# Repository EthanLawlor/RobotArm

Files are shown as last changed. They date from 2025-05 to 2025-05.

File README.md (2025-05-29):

# 🤖 Desktop Robot Arm

A compact, fully customizable desktop robot arm designed for small-scale automation tasks. Developed as part of a Bachelor of Engineering in Mechatronics at Technological University Dublin, this project integrates 3D-printed components, servo motor actuation, custom electronics, Arduino-based firmware, Bluetooth control, and an Android app interface.

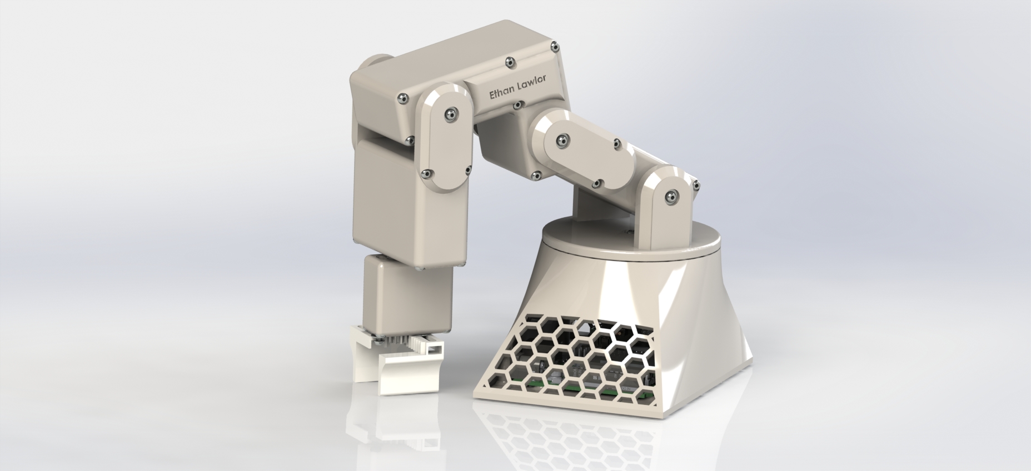
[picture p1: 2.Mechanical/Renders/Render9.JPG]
Robot Arm CAD Render
  
*Figure: CAD render of the assembled Desktop Robot Arm*

---

## 📦 Features

- 6 Degrees of Freedom using MG66R and SG90 servo motors  
- Bluetooth-enabled control with HC-05 and MIT App Inventor  
- Android app with presets and direct manual controls  
- Custom PCB with schematics and Gerber files (KiCAD)  
- Modular 3D-printed design with STL files included  
- Smooth servo motion using filtering algorithms  

---

## 📁 Repository Structure

1. **Documentation**  
   - `RobotArm-ProjectReport.pdf` – Full project report with design, testing, and results

2. **Electrical**  
   - `KiCAD-PCB/` – Circuit schematics, custom PCB layout, and Gerber files

3. **Mechanical**  
   - `STL-Files/` – 3D-printable mechanical components  
   - Includes exploded views and CAD drawings

4. **Software**  
   - `Arduino-Firmware/` – Code for ATmega328P (Arduino)  
   - `MIT-App-Inventor/` – Android app `.aia` source and `.apk` installer

---

## 🔧 Hardware Overview

- **Microcontroller:** ATmega328P (Arduino Uno or custom board)  
- **Servos:** 5× MG66R, 1× SG90  
- **Peak Current Draw:** 2.8A (measured)  
- **Bluetooth Module:** HC-05  
- **Build Volume:** 135mm x 90mm footprint  
- **Chassis:** Fully 3D-printed components (PLA)  

---

## 📱 Android App

- Built with **MIT App Inventor**  
- Control individual servo angles or trigger gesture presets:
  - `Home`, `Ready`, `Wave`, `Screwdriver`, `Circles`, `Diagonals`, `Worm`, `Demo`
- Bluetooth communication with Arduino via HC-05  

---

## 📐 Mechanical Design

- All STL files for 3D printing included  
- Exploded views, BOM, and design drawings available  
- Desktop-sized and modular for easy assembly and customization  

---

## 🔌 Electrical Design

- Custom PCB designed in **KiCAD**  
- Includes:
  - Circuit schematics  
  - PCB layout  
  - Gerber files for fabrication  
- Power and signal headers for servos, Bluetooth, and logic  

---

## 🧠 Arduino Firmware Features

- Servo smoothing for fluid movement  
- Bluetooth and Serial input parsing  
- Support for:
  - Comma-delimited angle commands (e.g., `90,90,90,90,90,90*`)
  - Keyword triggers (`Demo`, `Home`, etc.)
  - Real-time smoothing level adjustment (`0#/100#`)  

---

## 🚀 Getting Started

### 🔩 Requirements

- Arduino IDE  
- Android device with Bluetooth  
- 3D printer (recommended material: PLA)  
- 5V power supply (min. 3A)  
- HC-05 Bluetooth module  
- Basic tools for assembly and soldering  

### 🛠️ Setup Instructions

1. **3D Print** all components from the `STL-Files/` folder.  
2. **Assemble** using provided CAD diagrams.  
3. **Upload firmware** from `Arduino-Firmware/` to your ATmega328P.  
4. **Install Android app** from `MIT-App-Inventor/` (`.apk`) or open `.aia` to modify.  
5. **Pair Bluetooth** module and connect via the app.  
6. **Power on** the system and start experimenting!  

---

## 📚 Documentation

📄 Full design details, diagrams, testing results, and methodology can be found in the [Project Report (PDF)](./0.Documentation/RobotArm-ProjectReport.pdf).

---

## 🧩 Future Improvements

- Add tactile or force sensors  
- Integrate IoT control (Wi-Fi, MQTT)  
- Implement gesture learning via AI  
- Design swappable gripper attachments  
- Develop an educational kit version  

---

## 📝 License

This project is open-source and distributed under the terms of the [GNU General Public License v3.0 (GPL-3.0)](./LICENSE).

---

## 👤 Author

**Ethan Lawlor**  
B.Eng. Mechatronics  
Technological University Dublin

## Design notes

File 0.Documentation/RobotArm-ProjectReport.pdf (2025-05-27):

- i -

# Technological University Dublin Blanchardstown

## School of Informatics and Engineering

# ROBOT ARM

by

## Ethan Lawlor

### A report submitted in partial fulfillment of the requirements for:

ORDINARY BACHELOR OF ENGINEERING DEGREE IN MECHATRONICS

SUPERVISOR: | MARY LOOBY
SUBMISSION DATE: | 28/04/2024

- ii -

ABSTRACT

This report details the design and implementation of a versatile desktop robot arm, part of

the Mechatronics program at Technological University Dublin. Aimed at enhancing

efficiency in small-scale automation, the project addresses challenges in task

diversification, user-friendly customization, and seamless integration of critical

components like servos, Arduino Uno, and 3D-printed parts.

The introduction highlights the project's goal, emphasizing the need for improved

efficiency in desktop environments. The background section discusses limitations of

existing solutions and introduces the proposed robot arm. Scope and objectives outline a

focus on task versatility, user-friendly customization, and an educational component.

The literature review explores motor choices, motion algorithms, control systems, and

Bluetooth integration. The project design chapter covers mechanical specifications,

electrical architecture, software control flow, and critical success factors.

Materials and methods provide an overview of implementation, including software and

hardware prototyping, experimentation, and future plans for semester 2. Results and

discussion sections present data and interpretations, addressing project objectives.

Conclusions and recommendations synthesize the project's significance, evaluate success,

and suggest future directions.

The report includes a bibliography and appendices containing project planning, extracts

from the project diary, design drawings, software code, relevant standards, and additional

technical appendices. Overall, the report showcases the desktop robot arm's evolution,

offering insights into small-scale automation and robotics for readers interested in

mechatronics.

- iii -

DECLARATION

The work submitted in this report is the results of the candidate’s own investigations and

has not been submitted for any other award. Where use has been made of the work of

other people it has been fully acknowledged and referenced.

Student Name

Ethan Lawlor

- iv -

TABLE OF CONTENTS

- v -

LIST OF FIGURES

Figure 1.Conceptual CAD drawing showcasing the integration of servos, Arduino Uno, and 3D-

Figure 2.Overall block diagram illustrating the integrated components and workflow of the

Figure 5.AT Command Mode of HC-05 and HC-06 Bluetooth Module with Shah Saifur Rahman

- 1 -

Chapter 1 Introduction

### 1.1 Problem: Enhancing Accessibility in Small-Scale Automation

Addressing the need for improved efficiency in small-scale automation within desktop

environments, this chapter introduces the project's goal: designing a versatile desktop robot arm

to cater to diverse user needs.

Key Challenges:

Task Diversification: Meeting the challenge of handling diverse tasks with precision, from

soldering to small cleaning operations in desktop environments.

User-Friendly Customization: Overcoming the lack of user-friendly customization in existing

solutions to allow users, regardless of technical expertise, to adapt the robot arm to unique

requirements.

Integration of Components: Ensuring seamless communication and functionality among critical

components like servos, Arduino Uno, and 3D-printed parts to optimize the robot arm's

performance.

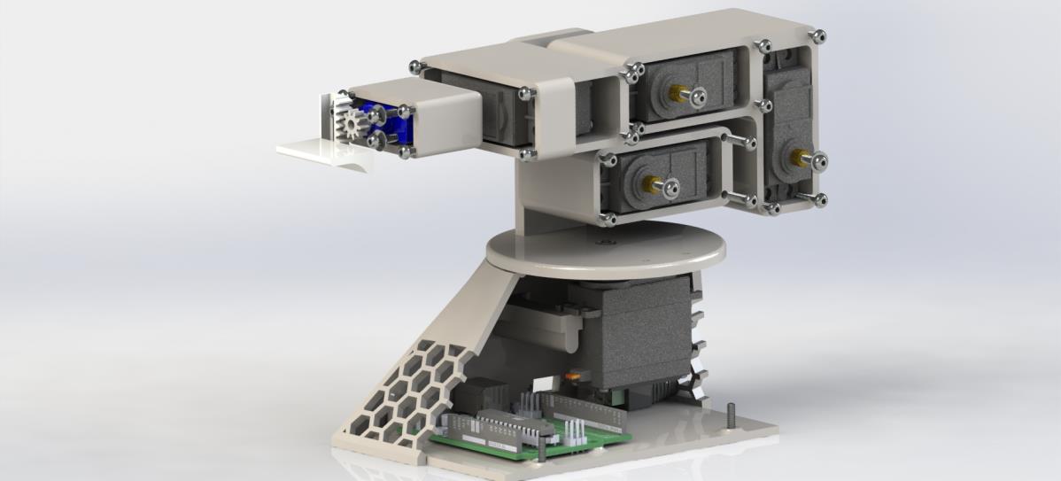
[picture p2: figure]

- 2 -

Figure 1.Conceptual CAD drawing showcasing the integration of servos, Arduino Uno, and 3D-printed

parts in the proposed desktop robot arm.

Solution Approach:

Visual representation of the proposed solution, illustrating the integration of servos for controlled

movements, Arduino Uno for automation programming, and 3D-printed parts for cost-effective

and customizable mechanical components.

Envisioning an accessible desktop robot arm, this project not only addresses challenges but also

serves as a learning platform, demystifying complexities for individuals regardless of their

automation background.

- 3 -

Figure 2.Overall block diagram illustrating the integrated components and workflow of the desktop robot

arm project.

### 1.2 Background

While automation technologies have evolved, applying robotic assistance in desktop

environments lacks innovation. Existing systems tailored for industrial settings fall short in

versatility for small-scale tasks. The project introduces a desktop robot arm to bridge this gap,

designed to handle diverse tasks efficiently.

Automation in Desktop Environments:

Covering a spectrum of tasks from intricate soldering to simple cleaning operations, existing

solutions lack adaptability. The desktop robot arm integrates servos, Arduino Uno, and 3D-

printed parts to ensure a harmonious collaboration for seamless task execution.

- 4 -

Challenges in Small-Scale Automation:

Small-scale automation demands precision, adaptability, and user-friendly customization. This

project provides a solution enhancing efficiency in desktop tasks while empowering users to

customize the robot arm according to specific requirements.

Related Work and Research:

Building upon collective knowledge, the project incorporates lessons learned from related work

to create a solution emphasizing adaptability, ease of use, and hands-on learning opportunities.

### 1.3 Scope and Objectives

Scope:

Task Versatility: Excel in a variety of small-scale tasks in desktop or workspace settings,

including soldering, cleaning, and precision activities.

User-Friendly Customization: Focus on providing an accessible platform for users to customize

and adapt the robot arm, catering to varying technical expertise levels.

Educational Component: Serve as an educational tool, offering hands-on learning experiences

in engineering and automation for students and DIY enthusiasts.

Objectives:

Design and Fabrication: Develop a robust and versatile desktop robot arm through the

integration of servos, Arduino Uno, and 3D-printed parts, ensuring precision and adaptability.

- 5 -

User-Friendly Interface: Implement an interface allowing individuals, regardless of technical

proficiency, to easily program and control the robot arm for different tasks.

Educational Integration: Create comprehensive documentation, including CAD models and

circuit schematics, to facilitate understanding and modification, encouraging a community of

learners, makers, and innovators.

Task Optimization: Optimize the robot arm's performance in executing small-scale tasks,

emphasizing efficiency and accuracy.

Out of Scope:

Industrial-Scale Automation: Focus on desktop and small-scale tasks, not designed for large-

scale industrial automation.

Complex Manufacturing Processes: While enhancing efficiency in various tasks, it does not

address complex manufacturing processes outside the scope of desktop applications.

Specialized Research Applications: Not delving into specialized research applications, aiming

to cater to a broad audience seeking a versatile desktop companion.

### 1.4 Document Overview

Navigating the evolution of the desktop robot arm project, this document begins with a

comprehensive exploration of the background in Chapter 1, establishing the context and

motivations. Each subsequent chapter provides balanced coverage, ensuring a detailed

exploration of the project.

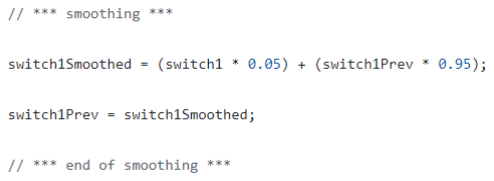
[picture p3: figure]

- 6 -

Chapter 2 Literature Review

### 2.1 Motors: Navigating Choices in Robotic Actuation

In the expansive realm of robotic projects, the perpetual dichotomy persists in the

selection of actuation mechanisms—specifically, the prevalent preference for either servo

motors or stepper motors (Motion Solutions, n.d.). A contemporary shift in this landscape

favors the adoption of the latest servo motors, distinguished by their heightened torque

capabilities. This choice is rooted in the quest for precision and dynamism, where the

newer servo motors emerge as the optimal solution for orchestrating intricate and agile

movements.

Figure 3. James Bruton Smoothing algorithm.

### 2.2 Motion Algorithm: Harmonizing Movement with James Bruton

James Bruton, the mastermind behind XRobots, introduces a sophisticated motion

algorithm designed to imbue motors with a seamless and aesthetically pleasing trajectory.

This algorithm tactically blends 97% of the last value with 3% of the new value in each

loop iteration, orchestrating a deliberate deceleration as the motor approaches the

culmination of its movement. The finesse of this algorithm lies in its ability to deliver not

just functionality but a visual elegance in robotic motion (XRobots, 2021).

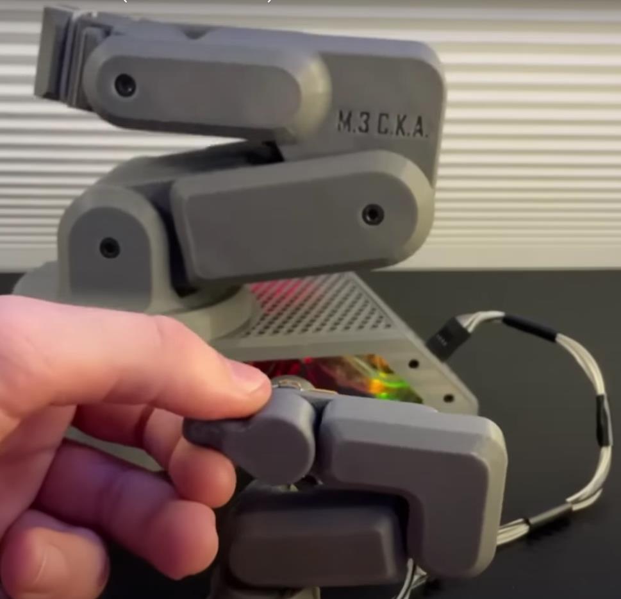
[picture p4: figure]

- 7 -

Figure 4. Kelton Serra's 1/3rd Scale Model Controller

### 2.3 Control: Kelton Serra's Ingenuity in Robotic Governance

In the domain of robotic control systems, Kelton Serra from Build Some Stuff offers a

nuanced and effective approach. Serra advocates for the construction of a 1/3 scale model

mirroring the robot's design, wherein rotary encoders replace the actual motors. The

result is a symbiotic relationship where the robot mirrors the movements of its scaled-

down counterpart. Beyond this inventive control mechanism, Serra's meticulous attention

extends to cable management within the robot arm, showcasing a commitment to both

functionality and aesthetics (Build Some Stuff, 2023).

- 8 -

Figure 5.AT Command Mode of HC-05 and HC-06 Bluetooth Module with Shah Saifur Rahman

### 2.4 Bluetooth Integration: Crafting Connectivity with Dejan Nedelkovski

A pervasive trend among makers involves the integration of wireless control functionality

into robot arms. This augmentation provides these devices with graphical interfaces

featuring intuitive sliders for controlling motor angles. Noteworthy in this realm is Dejan

Nedelkovski, the innovative mind behind HowToMechatronics. His contribution stands

out for its comprehensible system, leveraging MIT App Inventor and HC-05 Bluetooth

Modules to seamlessly integrate Bluetooth functionality into the robotic ecosystem

(HowToMechatronics, 2018).

### 2.4 Practical Bluetooth: Using HC-05 Module from Autodesk Instructables

This section explores practical Bluetooth integration using the HC-05 Module,

referencing Autodesk Instructables. It details the steps and considerations for

incorporating Bluetooth functionality into the robotic system, extending the project's

connectivity capabilities (Rahman, 2017).

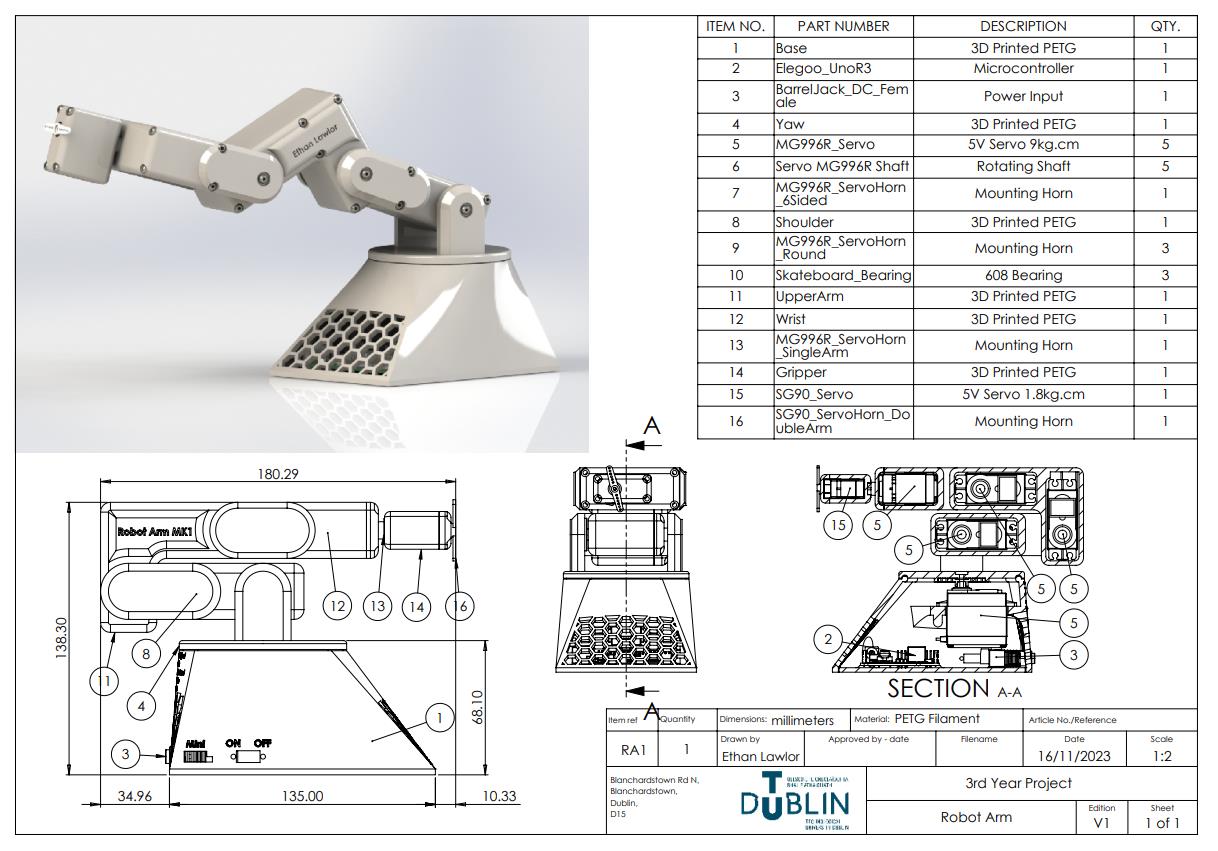
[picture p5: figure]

- 9 -

Chapter 3 Project Design

This chapter delves into the comprehensive design specifications of the project, providing

a outline of its operational parameters. The essence of the design is encapsulated through

detailed mechanical specifications, an electrical block diagram, and a software flowchart.

The agreed-upon Critical Success Factors are detailed within this section.

Figure 6.Solidworks Assembly BOM

### 3.1 Mechanical Design

The mechanical design is a pivotal aspect of the project, dictating its form and

functionality. Detailed CAD drawings, including subsections, will be presented to

elucidate the intricate details of the robotic arm. These drawings will provide insights into

the structural elements, component placements, and the overall architecture.

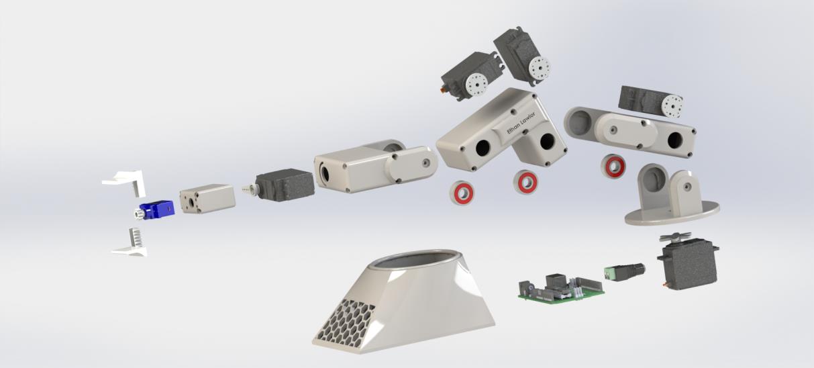
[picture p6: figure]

- 10 -

Figure 7.Exploded View of 3D CAD Model

The robot will have 6 degrees of freedom served by 5 MG66R Servo motors and 1 SG90

Servo. The footprint is 135mm by 90mm meaning it is small enough to keep on an

average sized desk.

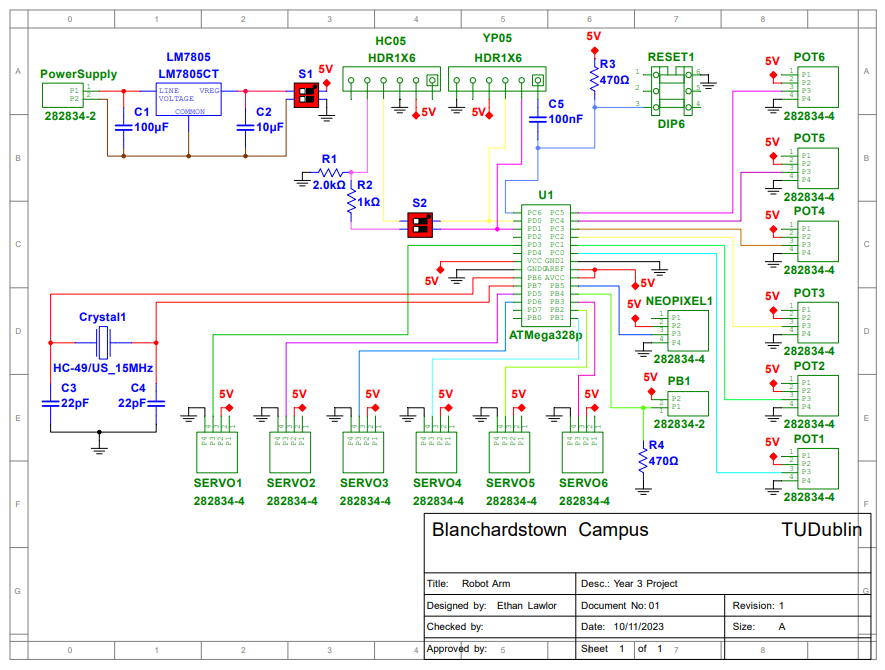
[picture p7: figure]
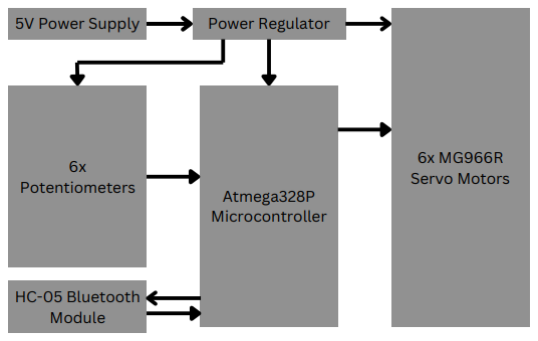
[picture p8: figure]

- 11 -

Figure 8. Electrical Schematic

### 3.2 Electrical Architecture

An integral facet of the project lies in its electrical architecture, governing the interactions

between components. The electrical block diagram will be presented to offer a visual

representation of the connections, interfaces, and dependencies among various electrical

elements. In this section, supporting CAD drawings illustrating the electrical components

and their arrangements should be seamlessly integrated.

Figure 9.Block Diagram

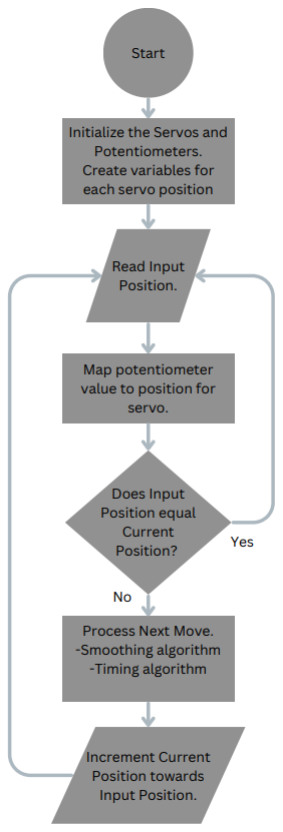
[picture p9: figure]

- 12 -

### 3.3 Software Control Flow

The control mechanism of the project is

orchestrated through a software flowchart.

This graphical representation elucidates the

sequence of operations and decision points

in the control system. It provides a holistic

view of how the software governs the

project's behavior. Supporting documents,

such as the actual software flowchart and

relevant code snippets, should be embedded

within | this | section | to | enhance

comprehension.

### 3.4 Critical Success Factors

Critical Success Factors (CSFs) represent the

key benchmarks that, when achieved, ensure

the project's success. At the very minimum

the robot arm should be able to pick up and

move a small mass from one point to another

on the a desk.

- 13 -

Chapter 4 Materials and Methods

### 4.1 Project Implementation Overview

In the journey of bringing our desktop robot arm to life, several crucial steps have been

undertaken to translate concepts into tangible progress.

### 4.1.1 Software Prototyping

Programming the Arduino Uno was a pivotal aspect of the project. The initial software

prototyping | focused | on | basic | automation | functionalities, | ensuring | seamless

communication between the servo motors and the control system. This iterative process

involved experimenting with different code snippets to refine the robot arm's

responsiveness.

Figure 10.Software Simulation

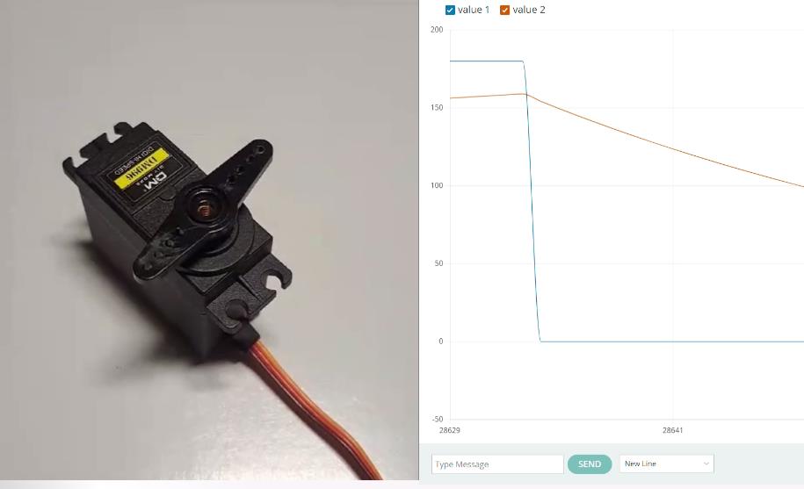
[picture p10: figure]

- 14 -

### 4.1.2 Hardware Prototyping

The foundational step involved testing the current consupmtion for the robot arm. Using a

combination table top power supply we called for the servos to make controlled

movements, and we successfully measured a value of 2.8Amps at peak. This value aligns

with the expected value drawn from datasheets.

Figure 11.Hardware Prototyping

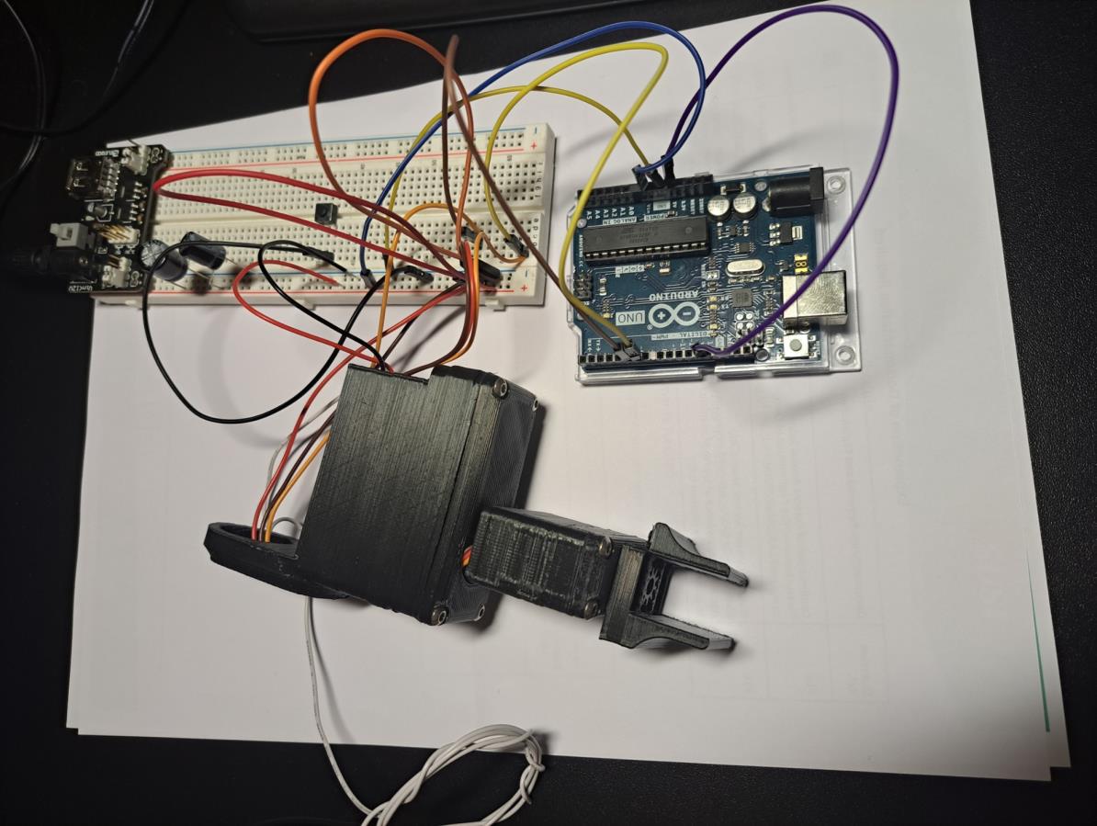
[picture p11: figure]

- 15 -

Figure 12.Experimental Print and Joint Movement

### 4.1.3 Experimentation and Concept Investigation

To validate our design choices, experimentation was conducted. The robot arm

underwent trial print and assembly to check the tolerances on various mating components

to make sure movement was not hindered by any unforeseen design flaws.

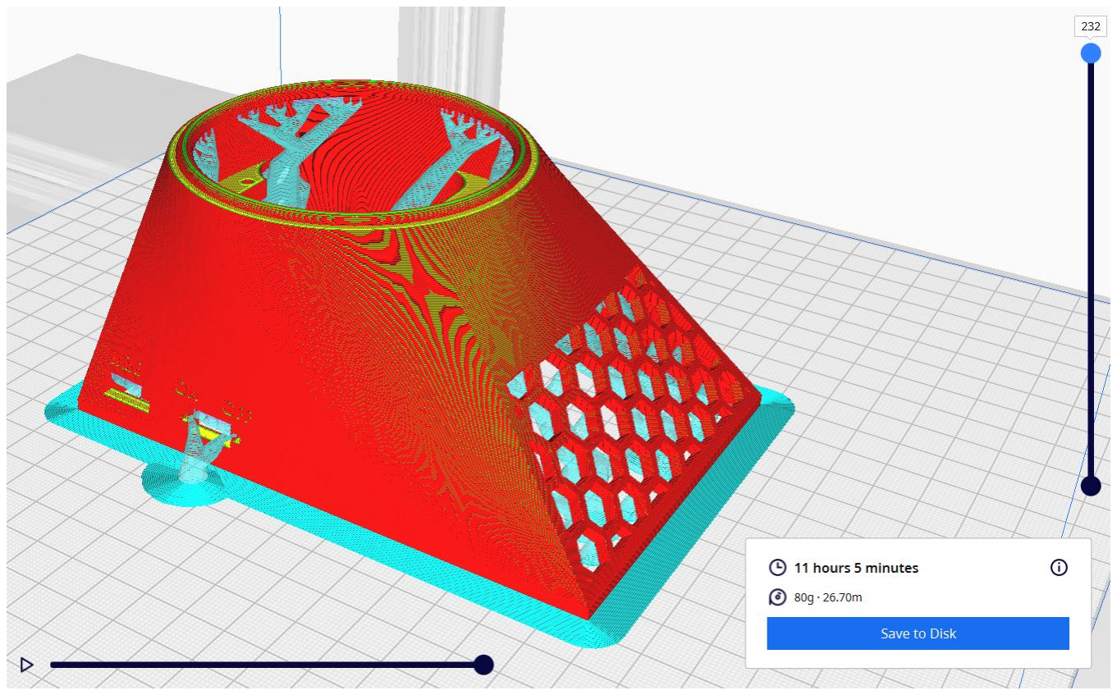
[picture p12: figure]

- 16 -

Figure 13.Cura Slicing Software Writing the G-Code for the 3D Printer.

### 4.2.1 Future Hardware

Looking ahead, we plan to implement the use of a 3D printer and its slicing software to

manufacture the remaining pieces required for the build. Then assembly of all the

components begins, this includes the integratration of the electrical wiring throughout the

assembly.

### 4.2.2 Software Refinements

In the software realm, refinements are on the horizon. With the aim being to optimize the

control algorithm, introducing more sophisticated motion planning to enhance the robot

arm's efficiency and fluidity in task execution.

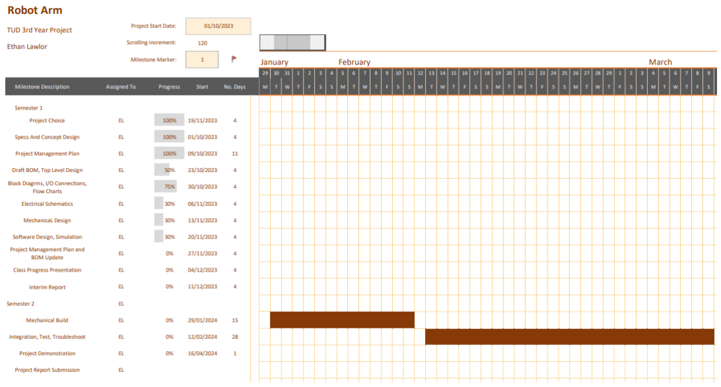
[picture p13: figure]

- 17 -

### 4.2.3 Timeline Plan

Our Semester 2 journey is mapped out in a Gantt chart, providing a visual roadmap.

Tasks such as hardware modifications, software refinements, and testing phases are

strategically planned to ensure a systematic and well-paced progression.

Figure 14.Gantt Chart

### 4.2.4 Explanation of Future Plans

The decisions driving our future plans are rooted in user feedback, technological

advancements, and a commitment to creating a versatile and user-friendly desktop robot

arm. We anticipate overcoming challenges and reaching new milestones as we refine and

expand the project.

- 18 -

### 4.3 Summary

This chapter encapsulates the strides made in hardware and software development,

showcasing our robot arm's evolution. Looking forward, Semester 2 promises exciting

conclusions, solidifying our commitment to innovation in small-scale automation.

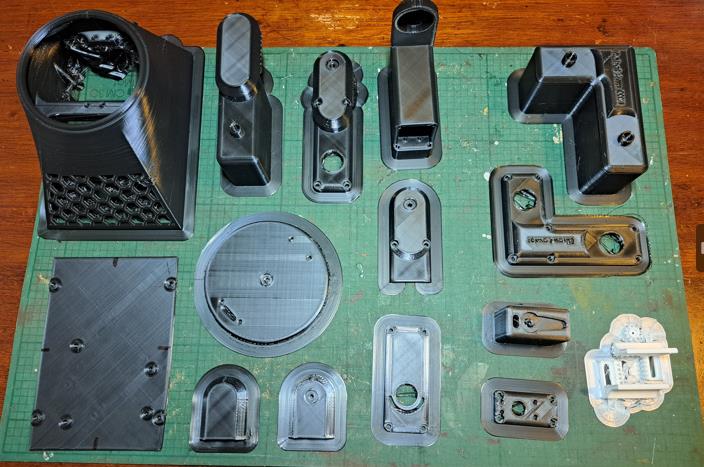
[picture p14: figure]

- 19 -

Chapter 5 Results and Discussion

### 5.1 Results

The project achieved several key milestones in developing the desktop robot arm:

- 3D Printing Completion: The entire structure of the robot arm was successfully

3D printed, meeting the design specifications and maintaining high dimensional

accuracy.

Figure 15.All Parts 3D Printed.

- Servo Motor Programming: All six servo motors were effectively programmed

to perform specific movements using the ATmega microcontroller unit (MCU),

demonstrating precise control and synchronization.

- 20 -
- Custom PCB Development: A custom PCB was developed using the same

ATmega chip, which streamlined the electrical connections and improved the

overall reliability of the system.

Figure 16.Custom PCB designed in KiCAD.

- Mobile App Development: A mobile application was created using MIT App

Inventor, allowing for intuitive and responsive control of the robot arm from a

smartphone.

Figure 17.Custom Android App designed in MITAppInventor.

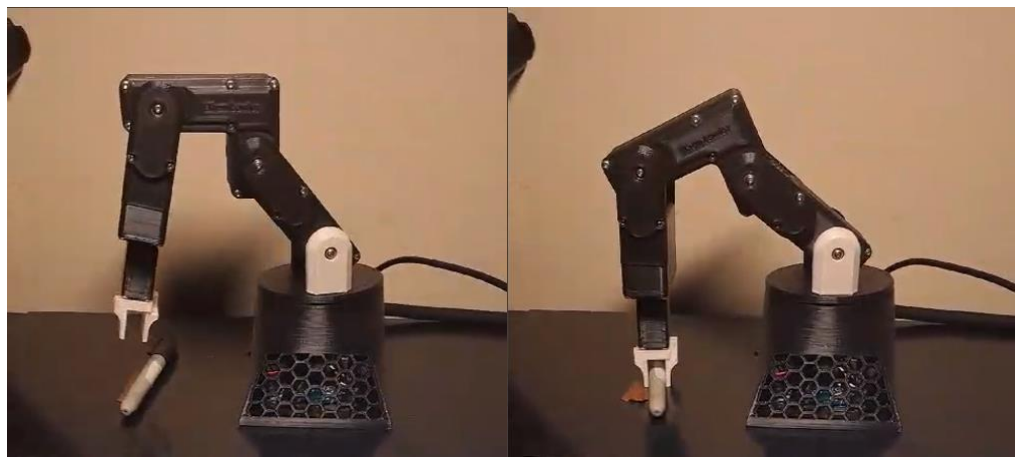
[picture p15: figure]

- 21 -
- Coordinated Movements: With the combined successes mentioned above, the

robot arm was able to be command to move, understand that command and

complete it establishing coordinated movements.

Figure 18.It Lives.

These achievements confirm the technical viability of the project components integrated

within the robot arm.

- 22 -

### 5.2 Discussion

The project's results underscore its success in integrating various technologies into a

functional desktop robot arm:

Performance of Servo Motors: The servo motors performed well, with movements that

were both precise and reliable. This is crucial for tasks requiring high accuracy and

repeatability.

Functionality of the Custom PCB: The custom PCB facilitated efficient electrical

routing and component organization, enhancing the system's stability and ease of

troubleshooting.

Usability of the Mobile App: The mobile app proved to be user-friendly, providing a

straightforward interface for controlling the robot arm. Its performance was robust, with

minimal latency and high reliability in command execution.

These outcomes demonstrate the project's effectiveness in achieving its goals of creating

a versatile and user-friendly desktop robot arm. Future work could focus on further

optimizing the design for energy efficiency and exploring the integration of additional

sensors for expanded capabilities.

- 23 -

Chapter 6 Conclusions and Recommendations

### 6.1 Conclusions

This desktop robot arm project has successfully integrated 3D printing, custom

electronics, and software to provide a functional tool for small-scale automation. It

illustrates an effective approach to combining diverse technologies to enhance efficiency

and adaptability in automation tasks.

- Project Importance: The project showcases how combining mechanical design,

precise electronic controls, and intuitive software can produce a functional

automation tool. This robot arm can be a model for future automation solutions

across various industries.

- Synthesis of the Project: The integration of 3D printed components,

programmed servo motors, and a user-friendly mobile app created a coherent

system. This model demonstrates how various elements can work together to

solve complex problems in automation.

- Global Perspective: The technologies used here could be adapted for broader

applications in manufacturing, healthcare, and education, promoting more

accessible and customizable automation solutions.

- 24 -

### 6.2 Recommendations

To expand the project's impact, the following areas could be explored:

- Integration of Advanced Sensors: Adding touch, pressure, and proximity

sensors could enable the robot arm to perform more delicate and responsive

operations.

- Development of AI Algorithms: Implementing machine learning could allow the

robot arm to improve its operations based on experience, enhancing performance

with minimal supervision.

- Expansion to IoT: Enabling IoT connectivity could facilitate remote operations

and coordination among multiple units.

- Sustainability Considerations: Future models should incorporate sustainable

materials and energy-efficient components to reduce environmental impact.

- Educational Kits: Creating educational kits from this project could provide

practical learning tools for aspiring engineers and makers.

Future Directions

Building on these recommendations could significantly enhance the robot arm’s

capabilities, turning it into a smarter automation tool and a platform for further

technological innovations.

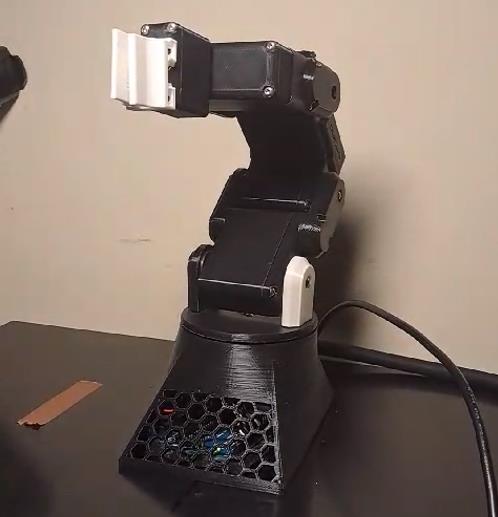
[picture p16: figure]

- 25 -

Figure 19.Fin.

In summary, this project not only fulfills its initial goals but also sets a robust

groundwork for future advancements in robotic technology. It demonstrates a scalable

and adaptable approach to automation that has significant potential for practical

applications and educational purposes. This work paves the way for innovations that

could extend the capabilities of desktop automation, enhancing both the efficiency and

accessibility of robotic solutions across various sectors.

- 26 -

## Bibliography

Bruton, J., 2021. github.com. [Online]

Available at: https://github.com/XRobots/ServoSmoothing

[Accessed 17/12/2023 December 2023].

Build Some Stuff, 2023. How I Built a 3D Printed Robot Arm from Scratch (Arduino Based).

[Online]

Available at: https://www.youtube.com/watch?v=5toNqaGsGYs

[Accessed 17 12 2023].

HowToMechatronics, 2018. DIY Arduino Robot Arm with Smartphone Control. [Online]

Available at: https://howtomechatronics.com/tutorials/arduino/diy-arduino-robot-arm-with-

smartphone-control/?utm_content=cmp-true

[Accessed 17 12 2023].

Motion Solutions, n.d. Servo Motor vs Stepper Motor: Which is right for your application?.

[Online]

Available at: https://www.motionsolutions.com/servo-motor-vs-stepper-motor-right-application/

[Accessed 17 12 2023].

Rahman, S. S., 2017. AT Command Mode of HC-05 and HC-06 Bluetooth Module. [Online]

Available at: https://www.instructables.com/AT-command-mode-of-HC-05-Bluetooth-module/

[Accessed 17 12 2023].

XRobots, 2021. ServoSmoothing. [Online]

Available at: https://github.com/XRobots/ServoSmoothing

[Accessed 17 Decemeber 2023].

XRobots, n.d. [Online].

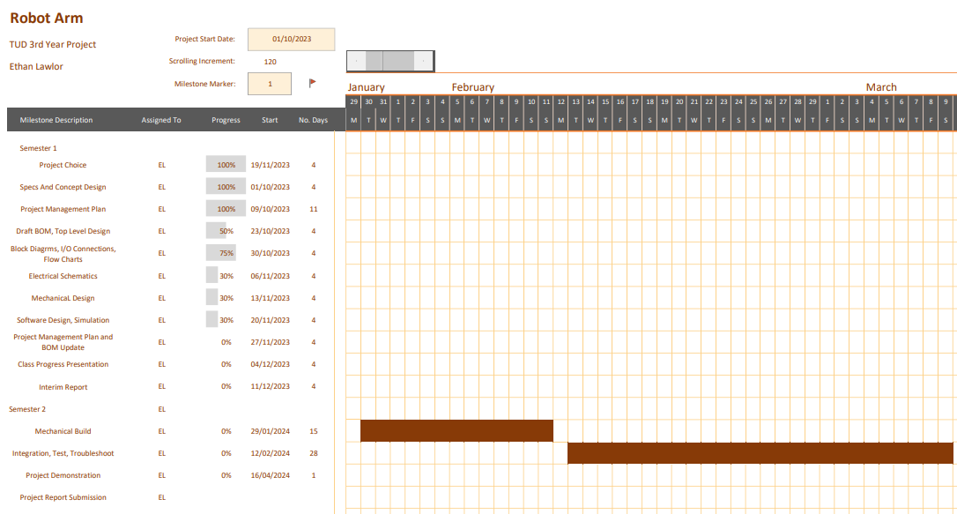
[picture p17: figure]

- 27 -

Appendix A Project Planning

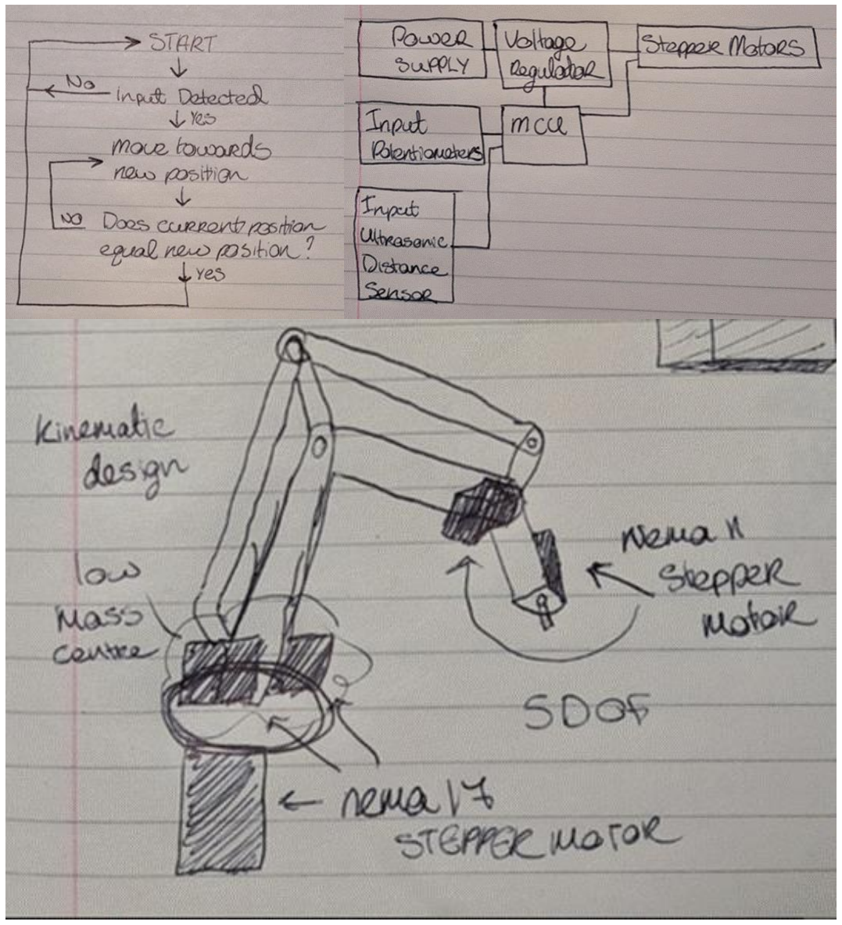
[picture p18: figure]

- 28 -

Appendix B Salient Extracts from Project Diary

- 29

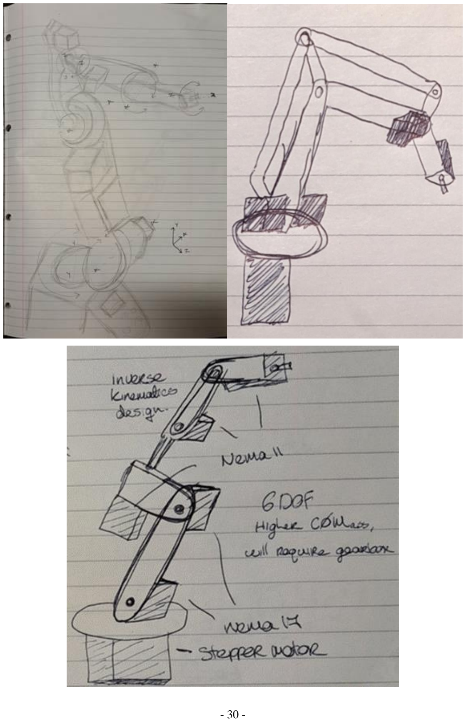
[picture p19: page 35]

- 30

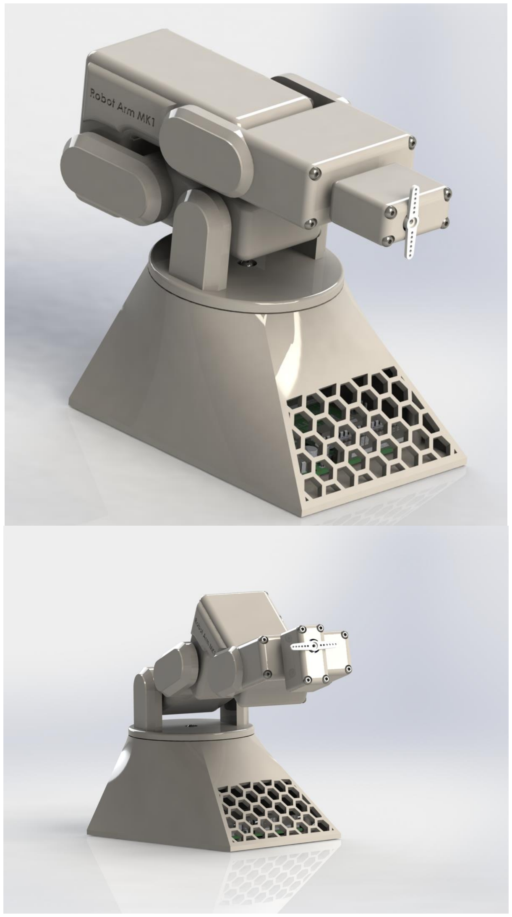
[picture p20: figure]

- 31 -

Appendix C Design Drawings & Component Specifications

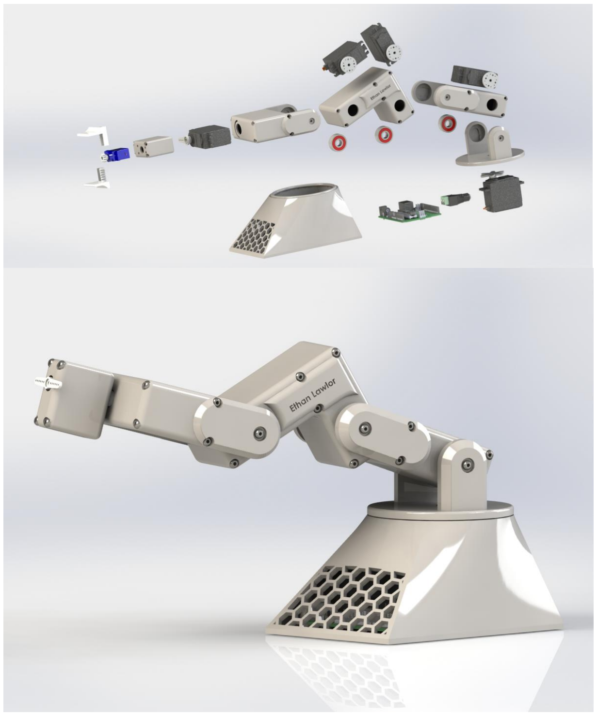
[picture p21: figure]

- 32

- 33

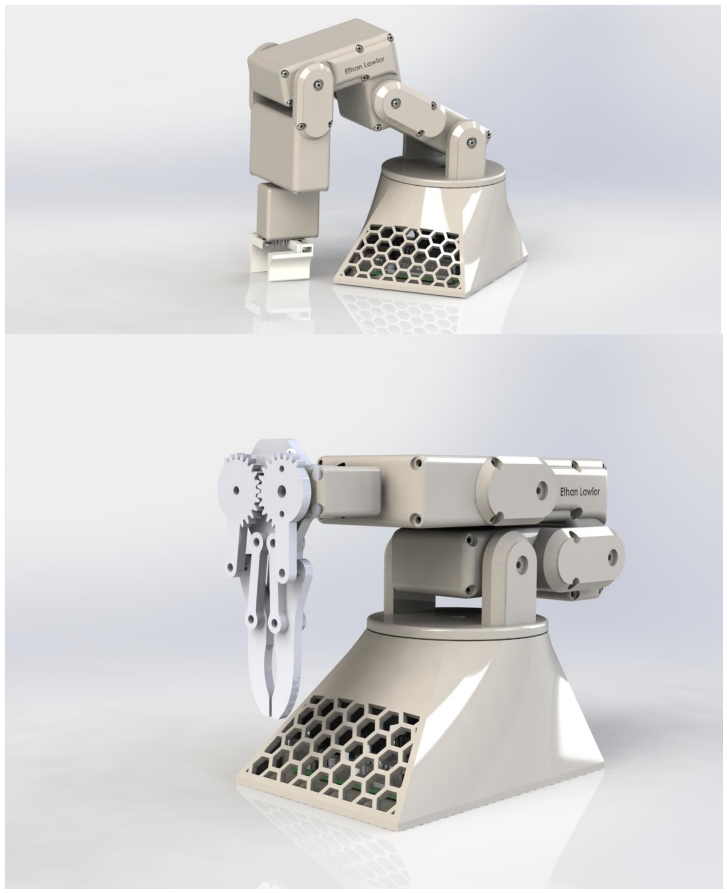
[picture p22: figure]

- 34

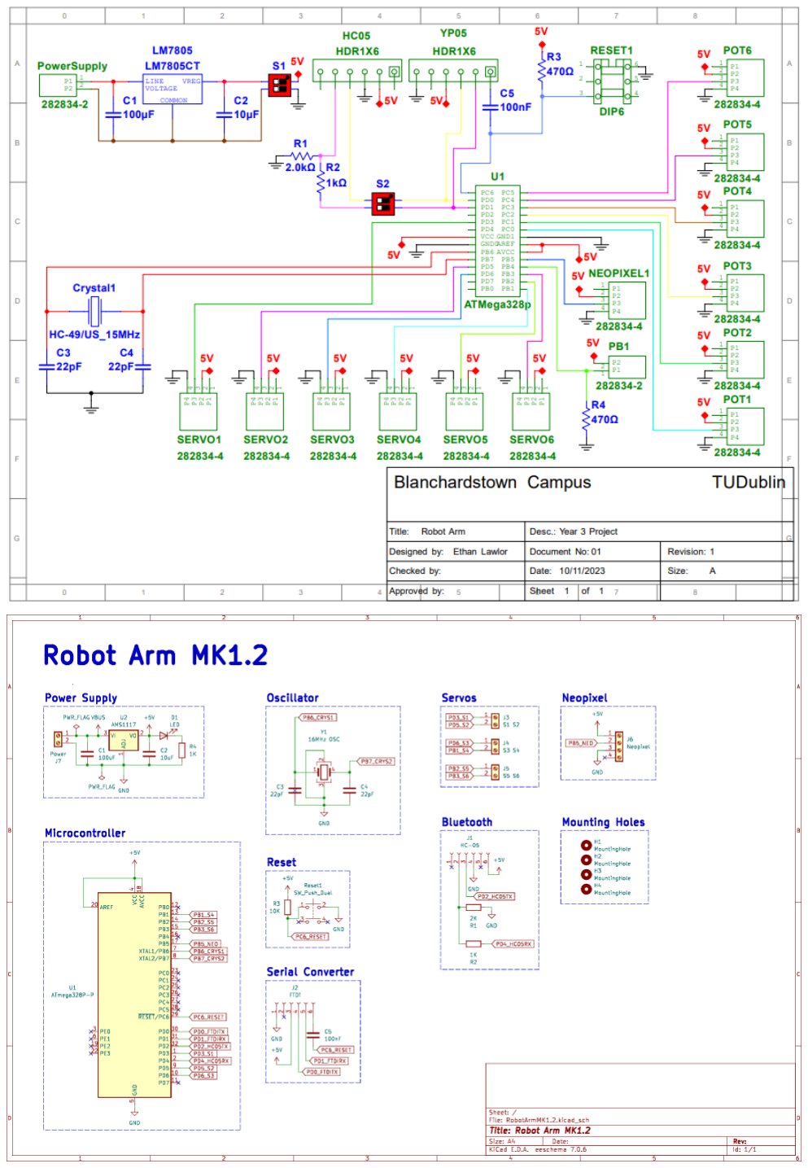
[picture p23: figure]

- 35 -

Appendix D Schematics

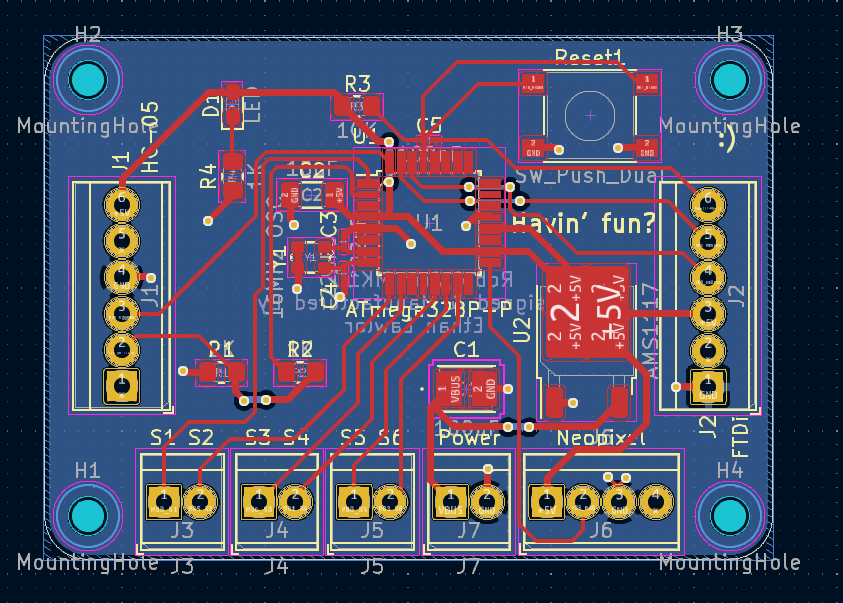
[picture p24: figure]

- 36

- 37 -

Appendix E List of Software Code – MITApp Inventor

https://gallery.appinventor.mit.edu/?galleryid=967702b1-feb8-411e-8451-febcac57ca8f

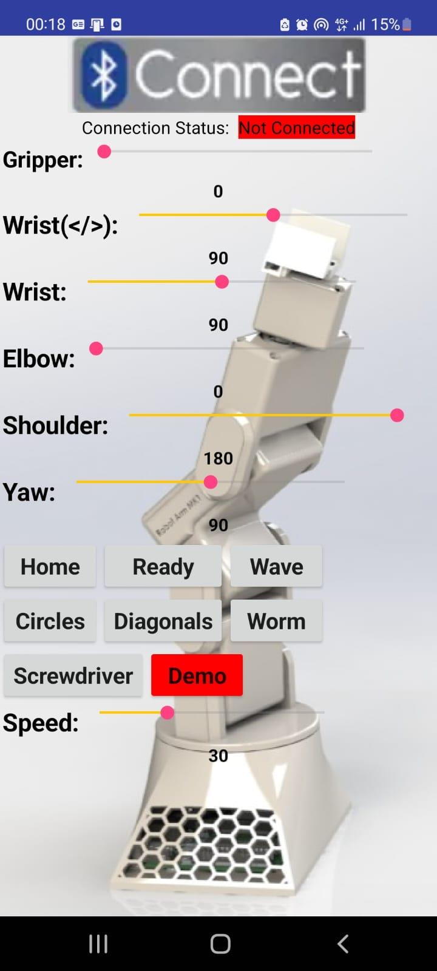
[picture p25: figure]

- 38

- 39 -

Appendix F List of Software Code - Arduino

// Ethan Lawlor

// B00149346

// Functionality of Code:
// Commands from Serial Monitor
// Commands from Bluetooth - MIT App Inventor
// Set individual servo angles - 0,0,0,0,0,0*/180,180,180,180,180,180* // Send groups of servo angles through keywords – Demo/Home/Ready/Wave // Set smoothing value - 0#/100#

#include <SoftwareSerial.h>

SoftwareSerial btSerial(2, 4);

#include <Servo.h>

Servo servo1;
Servo servo2;
Servo servo3;
Servo servo4;
Servo servo5;
Servo servo6;

int gripper;
int servo1pos;
float grippersmoothed;
float gripperPrev;

int switch2;
int servo2pos;
float switch2smoothed;
float switch2Prev;

int switch3;
int servo3pos;
float switch3smoothed;
float switch3Prev;

int switch4;
int servo4pos;
float switch4smoothed;
float switch4Prev;

- 40 -

int switch5;
int servo5pos;
float switch5smoothed;
float switch5Prev;

int switch6;
int servo6pos;
float switch6smoothed;
float switch6Prev;

const int servoPin1 = 3; // PWM pin for servo1 const int servoPin2 = 5; // PWM pin for servo2 const int servoPin3 = 6;
const int servoPin4 = 9; // PWM pin for servo4 const int servoPin5 = 10;
const int servoPin6 = 11; // PWM pin for servo6

const int open = 180;
const int close = 50;

char character;
String receivedData;
String angle_1;
String angle_2;
String angle_3;
String angle_4;
String angle_5;
String angle_6;

float smoothing = 0.03;
int servoDelay = 5;

int commaIndex;

void setup() {

Serial.begin(9600);
btSerial.begin(9600);

pinMode(servoPin1, OUTPUT); pinMode(servoPin2, OUTPUT); pinMode(servoPin3, OUTPUT); pinMode(servoPin4, OUTPUT); pinMode(servoPin5, OUTPUT); pinMode(servoPin6, OUTPUT);

- 41 -

servo1.attach(servoPin1);
servo2.attach(servoPin2);
servo3.attach(servoPin3);
servo4.attach(servoPin4);
servo5.attach(servoPin5);
servo6.attach(servoPin6);

Serial.println("<Arduino Ready>"); delay(1000);

Serial.println("");
Serial.print("Homing...");

smoothing = 0.010;
Serial.print("");
Serial.print("Smoothing = "); Serial.println(smoothing, 3);

servo6.write(90);
switch6 = 90;
servo6pos = 90;
switch6smoothed = 90;
switch6Prev = 90;

servo5.write(180);
switch5 = 180;
servo5pos = 180;
switch5smoothed = 180;
switch5Prev = 180;

servo4.write(0);
switch4 = 0;
servo4pos = 0;
switch4smoothed = 0;
switch4Prev = 0;

servo3.write(90);
switch3 = 90;
servo3pos = 90;
switch3smoothed = 90;
switch3Prev = 90;

servo2.write(90);
switch2 = 90;

- 42 -

servo2pos = 90;
switch2smoothed = 90;
switch2Prev = 90;

servo1.write(0);
gripper = 0;
servo1pos = 0;
grippersmoothed = 0;
gripperPrev = 0;

ready();
home();

smoothing = 0.03;
Serial.println("");
Serial.print("Finished Homing..."); Serial.print("");
Serial.print("Smoothing = "); Serial.println(smoothing);

Serial.println("");
Serial.println("<Robot Arm Ready>"); delay(1000);
}

void loop() {

readSerialData();

} // End of Loop

void readSerialData() {

while (Serial.available()) {
character = Serial.read(); receivedData = receivedData + character; checkAndExecute();
}

while (btSerial.available()) {
character = btSerial.read(); receivedData = receivedData + character; checkAndExecute();
}
}

- 43 -

void checkAndExecute() {

if (receivedData == "Home") { receivedData = "";
home();
}

if (receivedData == "Ready") { receivedData = "";
ready();
}

if (receivedData == "Wave") { wave();
receivedData = "";
}

if (receivedData == "Screwdriver") { receivedData = "";
screwdriver();
}

if (receivedData == "Circles") { receivedData = "";
circles();
}

if (receivedData == "Diagonals") { receivedData = "";
diagonals();
}

if (receivedData == "Worm") { receivedData = "";
worm();
}

if (receivedData == "Demo") { receivedData = "";
demo();
}

- 44 -

else if (character == '#') {

Serial.println("");
Serial.println(receivedData);
receivedData = receivedData.substring(0, receivedData.length() - 1); // Remove the last character '*'
int receivedStr = receivedData.toInt();
float smoothingRaw = map(receivedStr, 0, 100, 1, 90);
smoothing = smoothingRaw / 1000;
Serial.print("");
Serial.print("Smoothing = "); Serial.println(smoothing, 3);

receivedData = "";

}

else if (character == '*') {
Serial.println("");
Serial.println(receivedData);
receivedData = receivedData.substring(0, receivedData.length() - 1); // Remove the last character '*'
commaIndex = receivedData.indexOf(',');
angle_1 = receivedData.substring(0, commaIndex);
receivedData = receivedData.substring(commaIndex + 1);

commaIndex = receivedData.indexOf(',');
angle_2 = receivedData.substring(0, commaIndex); receivedData = receivedData.substring(commaIndex + 1);

commaIndex = receivedData.indexOf(',');
angle_3 = receivedData.substring(0, commaIndex); receivedData = receivedData.substring(commaIndex + 1);

commaIndex = receivedData.indexOf(',');
angle_4 = receivedData.substring(0, commaIndex); receivedData = receivedData.substring(commaIndex + 1);

commaIndex = receivedData.indexOf(',');
angle_5 = receivedData.substring(0, commaIndex); angle_6 = receivedData.substring(commaIndex + 1);

gripper = angle_1.toInt();
switch2 = angle_2.toInt();
switch3 = angle_3.toInt();

- 45 -

switch4 = angle_4.toInt(); switch5 = angle_5.toInt(); switch6 = angle_6.toInt();

receivedData = "";

moveServos();
}
}

void moveServos() {

Serial.println("");
Serial.print("Moving..."); Serial.print("");
Serial.print("Smoothing = ");
Serial.println(smoothing, 3);

while (servo1pos != gripper || servo2pos != switch2 || servo3pos != switch3 || servo4pos != switch4 || servo5pos != switch5 || servo6pos != switch6) {

readSerialData();

// ** smoothing ** //

grippersmoothed = (gripper * smoothing) + (gripperPrev * (1 -smoothing));
gripperPrev = grippersmoothed;
servo1pos = round(grippersmoothed);

switch2smoothed = (switch2 * smoothing) + (switch2Prev * (1 -smoothing));
switch2Prev = switch2smoothed;
servo2pos = round(switch2smoothed);

switch3smoothed = (switch3 * smoothing) + (switch3Prev * (1 -smoothing));
switch3Prev = switch3smoothed;
servo3pos = round(switch3smoothed);

switch4smoothed = (switch4 * smoothing) + (switch4Prev * (1 -smoothing));
switch4Prev = switch4smoothed;
servo4pos = round(switch4smoothed);

- 46 -

switch5smoothed = (switch5 * smoothing) + (switch5Prev * (1 -smoothing));
switch5Prev = switch5smoothed;
servo5pos = round(switch5smoothed);

switch6smoothed = (switch6 * smoothing) + (switch6Prev * (1 -smoothing));
switch6Prev = switch6smoothed;
servo6pos = round(switch6smoothed);

// ** end of smoothing ** //

servo1.write(servo1pos);
servo2.write(servo2pos);
servo3.write(servo3pos);
servo4.write(servo4pos);
servo5.write(servo5pos);
servo6.write(servo6pos);

delay(servoDelay);
}
}

void home() {

Serial.println("");
Serial.println("Home");
gripper = close;
switch2 = 90;
switch3 = 90;
switch4 = 0;
switch5 = 180;
switch6 = 90;
moveServos();
}

void ready() {

Serial.println("");
Serial.println("Ready");
gripper = 0;
switch2 = 0;
switch3 = 135;
switch4 = 90;

- 47 -

switch5 = 135;
switch6 = 90;
moveServos();
}

void wave() {

Serial.println("");
Serial.println("Wave");
gripper = close;
switch2 = 0;
switch3 = 135;
switch4 = 90;
switch5 = 135;
switch6 = 90;
moveServos();

gripper = open;
switch2 = 180;
switch6 = 105;
moveServos();

gripper = close;
switch2 = 0;
switch6 = 75;
moveServos();
}

void circles() {
Serial.println("");
Serial.println("Circles");

// Initial positions to start drawing circles
switch6 = 90;
switch5 = 130; // Base position - slightly rotate if needed for better motion
switch4 = 90; | // Elbow - mid position
switch3 = 90; | // Wrist - starting position
moveServos();
delay(1000); // Wait a bit before starting the circles

float previousValue = smoothing;
smoothing = previousValue * 25;
for (int i = 0; i < 5; i++) { | // Draw 5 circles

- 48 -

for (int angle = 0; angle < 360; angle += 10) { // Complete a circle in steps
// Simulate circular motion by adjusting elbow and wrist
switch4 = 90 + 10 * cos(angle * PI / 180); // Elbow - adjust for circular motion
switch3 = 90 + 10 * sin(angle * PI / 180); // Wrist - adjust for circular motion

// Optionally, slightly rotate the base to enhance the circular drawing effect
switch5 = 90 + 10 * cos(angle * PI / 180); // Base - slight rotation
switch6 = 90 + 30 * sin(angle * PI / 180); // Base - slight rotation

moveServos();
}
}
smoothing = previousValue; }

void worm() {
Serial.println("");
Serial.println("Worm");

switch6 = 90;
switch5 = 130;
switch4 = 90;
switch3 = 90;
moveServos();
delay(1000);

float previousValue = smoothing;
smoothing = 0.50;

for (int i = 0; i < 5; i++) { // Draw 5 circles for (int angle = 0; angle < 360; angle += 10) {

switch4 = 90 + 30 * cos(angle * PI / 180); switch3 = 90 + 30 * sin(angle * PI / 180); switch5 = 90 + 15 * sin(angle * PI / 180);

moveServos();
}
}

- 49 -

smoothing = previousValue; }

void diagonals() {
Serial.println("");
Serial.println("Diagonals");

switch6 = 90;
switch5 = 130; // Base position - slightly rotate if needed for better motion
switch4 = 90; | // Elbow - mid position
switch3 = 90; | // Wrist - starting position
moveServos();
delay(1000); // Wait a bit before starting the circles

float previousValue = smoothing;
smoothing = 0.50;

for (int i = 0; i < 5; i++) { // Draw 5 circles for (int angle = 0; angle < 360; angle += 10) {

switch3 = 90 + 15 * sin(angle * PI / 180); switch6 = 90 + 30 * sin(angle * PI / 180); moveServos();
}
}
smoothing = previousValue; }

void screwdriver() {

Serial.println("");
Serial.println("Screw Driver"); gripper = 180;
switch2 = 90;
switch3 = 180;
switch4 = 140;
switch5 = 45;
switch6 = 0;
moveServos();

switch3 = 160;
switch4 = 120;
switch5 = 30;
moveServos();

- 50

gripper =

0

;
moveServos()

;

smoothing = 0.01

;
delay

(500

)

;

switch4 = 140

;
switch5 = 45

;
moveServos()

;

switch3 = 70

;
switch4 = 90

;
switch5 = 110

;
switch6 = 90

;
moveServos()

;
delay

(1000

)

;

gripper =

0

;
switch2 = 90

;
switch3 = 120

;
switch4 = 90

;
switch5 = 110

;
switch6 = 90

;
moveServos()

;

gripper = 180

;
moveServos()

;

smoothing = 0.03

;
}

void demo()

{
home()

;
ready()

;
home()

;
ready()

;
home()

;
ready()

;
home()

;
diagonals()

;
worm()

;
circles()

;
}

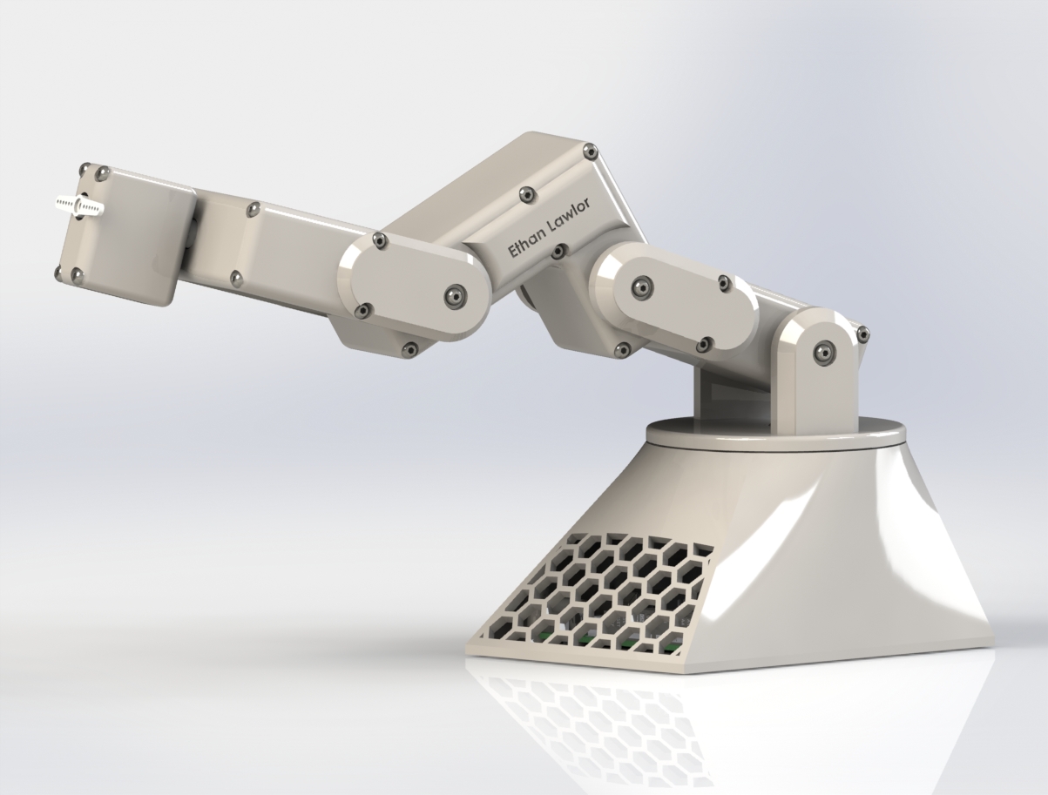
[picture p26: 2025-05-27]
2.Mechanical/Renders/Render6.JPG

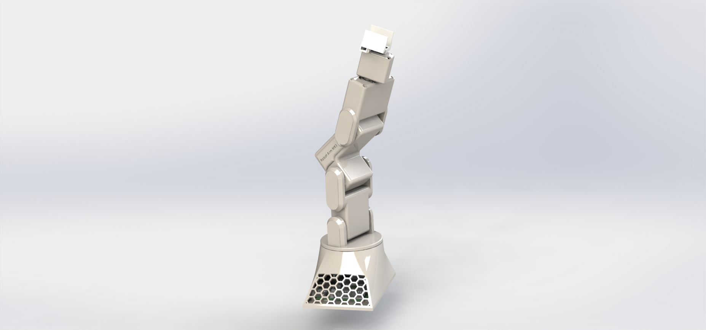
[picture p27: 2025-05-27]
2.Mechanical/Renders/Render13.JPG

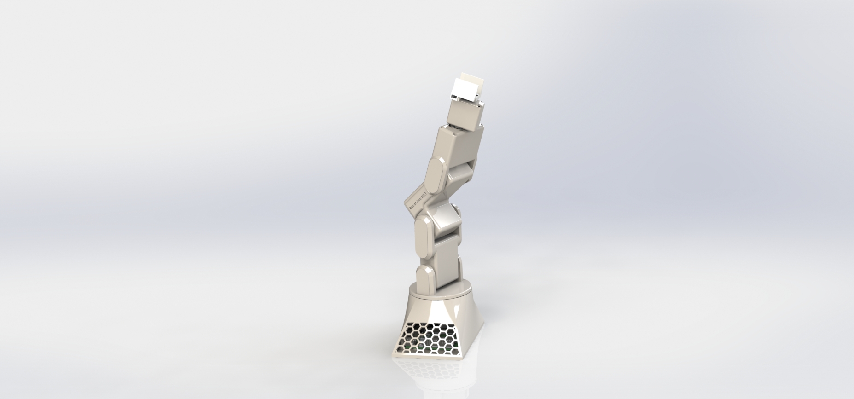
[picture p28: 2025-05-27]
2.Mechanical/Renders/Render14.JPG

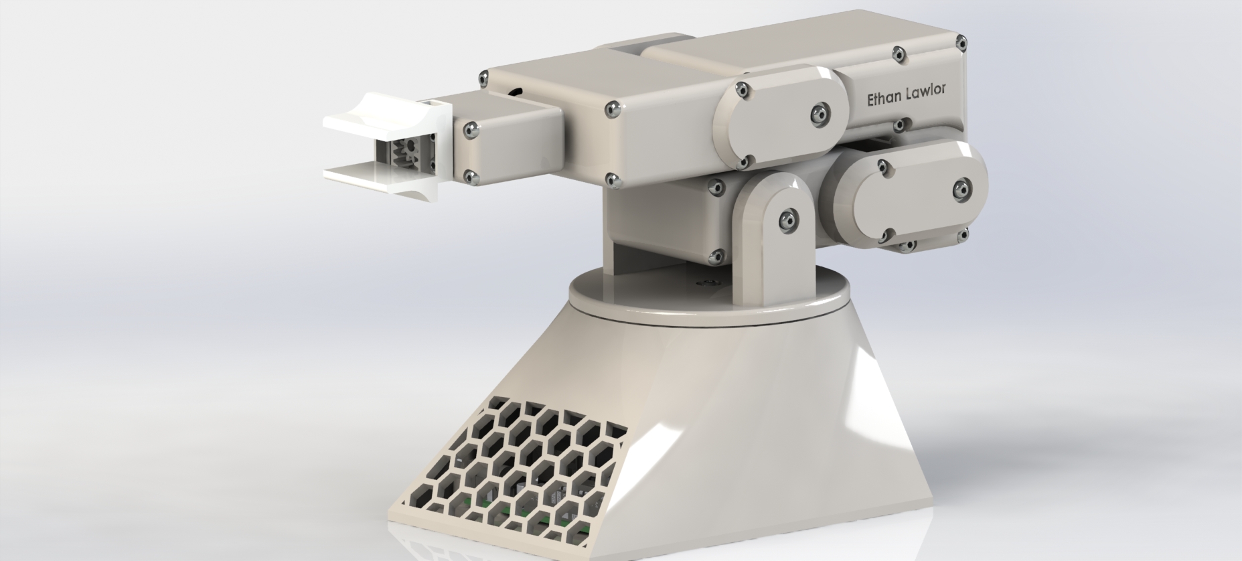
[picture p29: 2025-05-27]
2.Mechanical/Renders/Render11.JPG

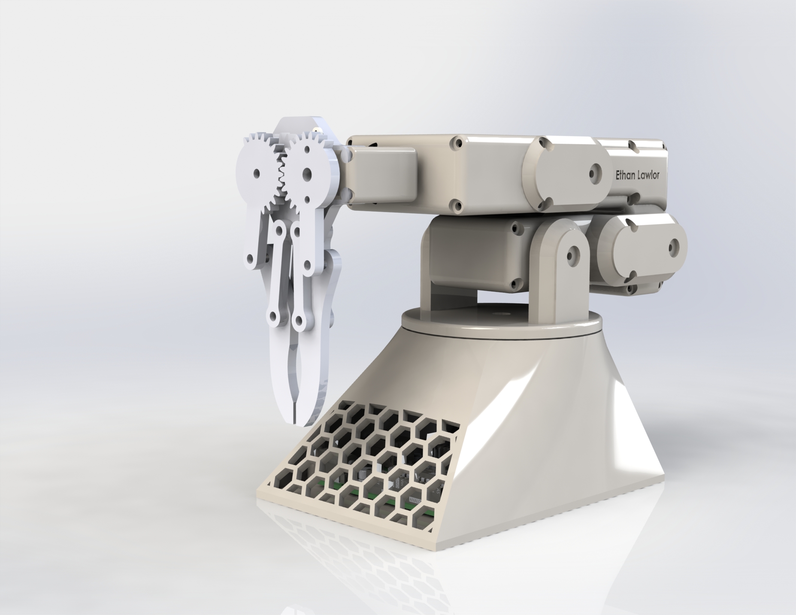
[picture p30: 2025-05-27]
2.Mechanical/Renders/Render8.JPG

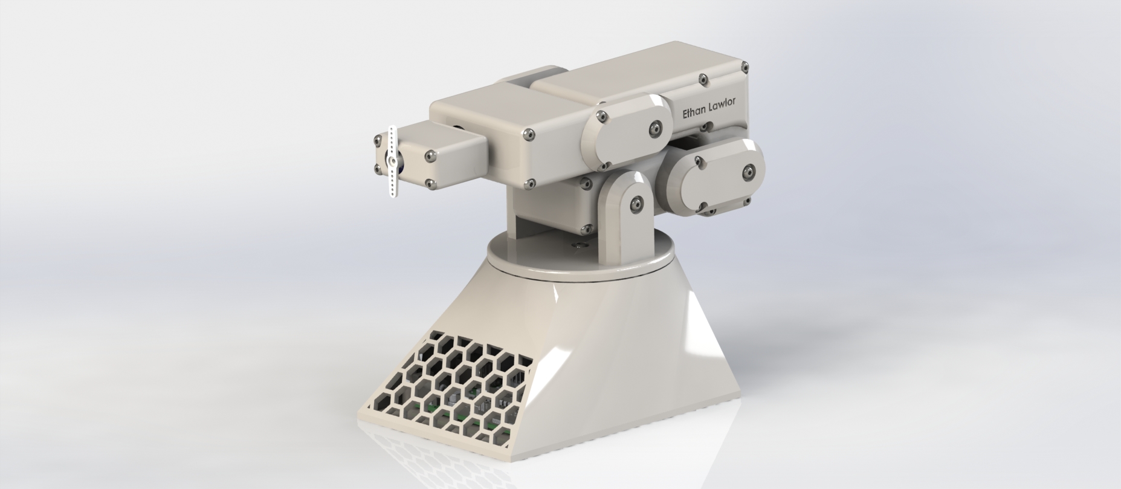
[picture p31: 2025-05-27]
2.Mechanical/Renders/Render2.JPG

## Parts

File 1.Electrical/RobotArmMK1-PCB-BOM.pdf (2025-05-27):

Bill of Materials (From Documen (Printed Date: Friday 1 March 2024, 14:07:05)

Quantity | Description | RefDes | Package | Type | Obsolete | Vendor | Status | Price
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
1 | Def, ATMega328p | U1 | Ultiboard\SDIP28 | No
1 | VOLTAGE_REGULATOR, LM7805CT | LM7805 | Texas Instruments\TO-220-3(NDE) | No
4 | TERMINAL_BLOCKS, 282834-2 | PowerSupply, SERVO 12, SERVO34, SERV O56 | TE Connectivity\282834-2 | No
1 | CRYSTAL, HC-49/US_15MHz | Crystal1 | Generic\HC-49US | No
1 | RESISTOR, 1kΩ | R2 | IPC-2221A/2222\RES1300-700X250 | -
1 | RESISTOR, 2.0kΩ | R1 | IPC-2221A/2222\RES1300-700X250 | -
1 | CAPACITOR, 100nF | C5 | IPC-2221A/2222\CAPPR250-630X1120 | -
2 | HEADERS_TEST, HDR1X6 | FTDI, HC05 | Generic\HDR1X6 | No
1 | SOCKETS, DIP6 | RESET1 | Generic\DIP-6 | No
1 | RESISTOR, 10kΩ | R3 | IPC-2221A2222\RES1300-700X250 | -
1 | CAPACITOR, 22pF | C4 | IPC-2221A/2222\CAPR250-500X250X550 | -
1 | CAPACITOR, 22pF | C3 | IPC-2221A2222\CAPR250-500X250X550 | -
1 | CAPACITOR, 100µF | C1 | IPC-2221A2222\CAPPR250-630X1120 | -
1 | CAPACITOR, 10µF | C2 | IPC-2221A2222\CAPPR250-630X1120 | -
1 | TERMINAL_BLOCKS, 282834-4 | NEOPIXEL1 | TE Connectivity\282834-4 | No

Hyperlink | Manufacturer | Manufacturer Part No. | Vendor Part No.

TE Connectivity

TE Connectivity

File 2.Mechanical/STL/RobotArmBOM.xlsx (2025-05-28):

Project: | Date:
Robot Arm MK1 | 2024-01-26
3D Printing BOM:
Part | Quantity | Filament (g) | Supports (%) | Time (H:M) | Printed
Base-Body | 1 | 60 | 8 | 8:57:00
Base-Lid | 1 | 24 | 4 | 3:07:00
Gripper-Body | 1 | 8 | 6 | 1:08:00
Gripper-Gear | 1 | 1 | 16 | 0:06:00
Gripper-Lid | 1 | 2 | 11 | 0:21:00
Gripper-Rack | 2 | 3 | 13 | 0:35:00
Shoulder-Body | 1 | 26 | 12 | 3:16:00
Shoulder-Lid | 1 | 11 | 18 | 1:39:00
UpperArm-Body | 1 | 36 | 4 | 4:20:00
UpperArm-Lid | 1 | 10 | 6 | 1:28:00
Wrist-Arm | 1 | 6 | 11 | 0:49:00
Wrist-Body | 1 | 23 | 5 | 3:00:00
Wrist-Lid | 1 | 5 | 9 | 0:39:00
Yaw-Body | 1 | 17 | 11 | 2:10:00
Yaw-Left | 1 | 4 | 10 | 0:31:00
Yaw-Right | 1 | 4 | 15 | 0:39:00
 | Total = | 240 | 9.94 | 32:45:00

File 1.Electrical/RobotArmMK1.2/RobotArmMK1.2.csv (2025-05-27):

# | Reference | Qty | Value | Footprint | DNP
1 | C1 | 1 | 100uF | PCBFootprints:TAJB_AVX-M
2 | C2 | 1 | 10uF | Capacitor_SMD:C_1206_3216Metric_Pad1.33x1.80mm_HandSolder
3 | C3, C4 | 2 | 22pF | Capacitor_SMD:C_0201_0603Metric_Pad0.64x0.40mm_HandSolder
4 | C5 | 1 | 100nF | Capacitor_SMD:C_0201_0603Metric_Pad0.64x0.40mm_HandSolder
5 | D1 | 1 | LED | LED_SMD:LED_0603_1608Metric_Pad1.05x0.95mm_HandSolder
6 | H1, H2, H3, H4 | 4 | MountingHole | MountingHole:MountingHole_2.2mm_M2
7 | J1 | 1 | HC-05 | TerminalBlock_TE-Connectivity:TerminalBlock_TE_282834-6_1x06_P2.54mm_Horizontal
8 | J2 | 1 | FTDi | TerminalBlock_TE-Connectivity:TerminalBlock_TE_282834-6_1x06_P2.54mm_Horizontal
9 | J3 | 1 | S1 S2 | TerminalBlock_TE-Connectivity:TerminalBlock_TE_282834-2_1x02_P2.54mm_Horizontal
10 | J4 | 1 | S3 S4 | TerminalBlock_TE-Connectivity:TerminalBlock_TE_282834-2_1x02_P2.54mm_Horizontal
11 | J5 | 1 | S5 S6 | TerminalBlock_TE-Connectivity:TerminalBlock_TE_282834-2_1x02_P2.54mm_Horizontal
12 | J6 | 1 | Neopixel | TerminalBlock_TE-Connectivity:TerminalBlock_TE_282834-4_1x04_P2.54mm_Horizontal
13 | J7 | 1 | Power | TerminalBlock_TE-Connectivity:TerminalBlock_TE_282834-2_1x02_P2.54mm_Horizontal
14 | R1 | 1 | 2K | Resistor_SMD:R_0805_2012Metric_Pad1.20x1.40mm_HandSolder
15 | R2, R4 | 2 | 1K | Resistor_SMD:R_0805_2012Metric_Pad1.20x1.40mm_HandSolder
16 | R3 | 1 | 10K | Resistor_SMD:R_0805_2012Metric_Pad1.20x1.40mm_HandSolder
17 | Reset1 | 1 | SW_Push_Dual | Button_Switch_SMD:SW_Push_1P1T_NO_6x6mm_H9.5mm
18 | U1 | 1 | ATmega328P-P | Package_QFP:TQFP-32_7x7mm_P0.8mm
19 | U2 | 1 | AMS1117 | Package_TO_SOT_SMD:TO-252-2
20 | Y1 | 1 | 16MHz OSC | Oscillator:Oscillator_SMD_ECS_2520MV-xxx-xx-4Pin_2.5x2.0mm

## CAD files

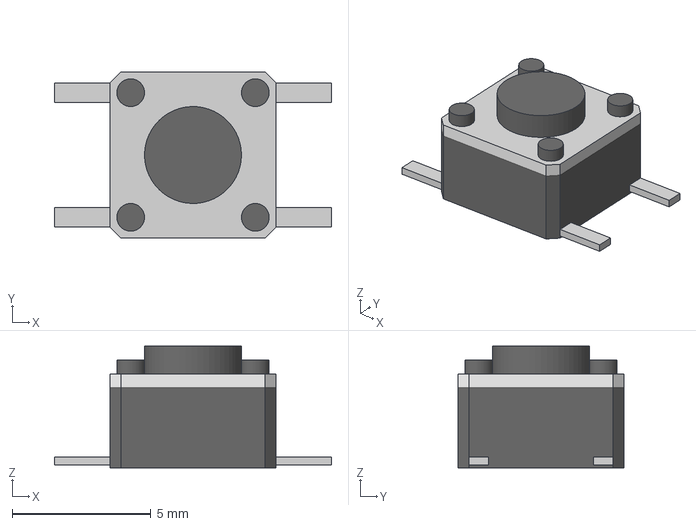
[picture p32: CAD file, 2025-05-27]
1.Electrical/RobotArmMK1.2/stepfiles/PZ_PushButton.stp
10.0 x 6.00 x 4.40 mm

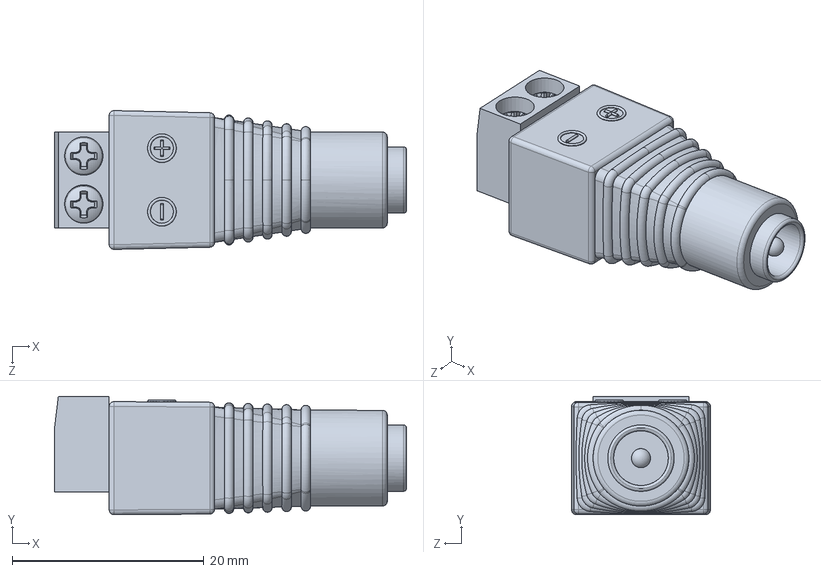
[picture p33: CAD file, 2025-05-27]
2.Mechanical/Solidworks/PackAndGo/BarrelJack_DC_Female.SLDPRT
36.7 x 12.3 x 14.5 mm

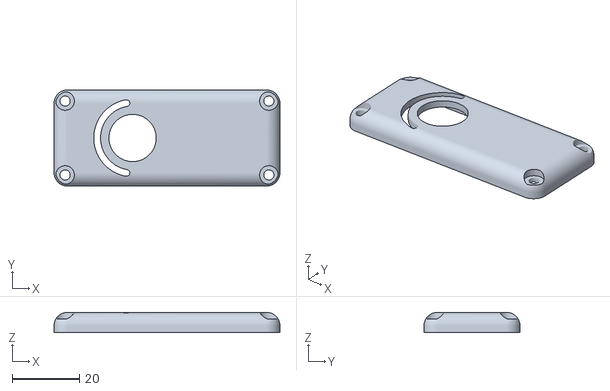
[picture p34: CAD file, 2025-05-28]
2.Mechanical/STL/Wrist-Lid.STL
67.0 x 28.5 x 6.00

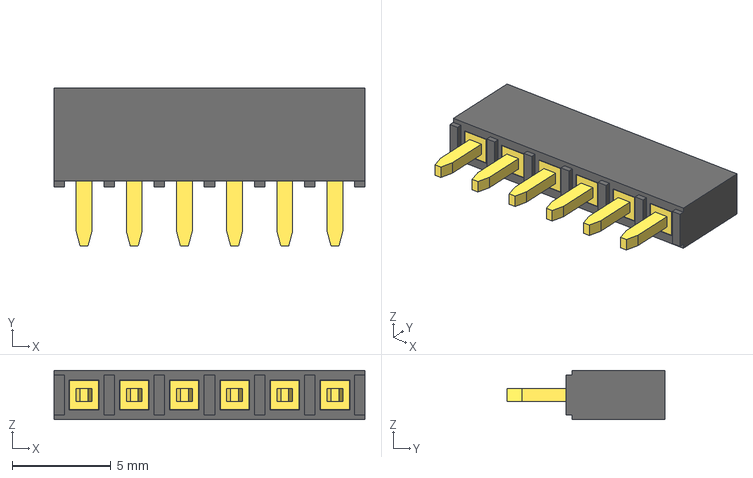
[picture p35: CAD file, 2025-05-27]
1.Electrical/RobotArmMK1.2/stepfiles/6-Pin Header - Female - 2.54mm.step
15.7 x 8.00 x 2.50 mm

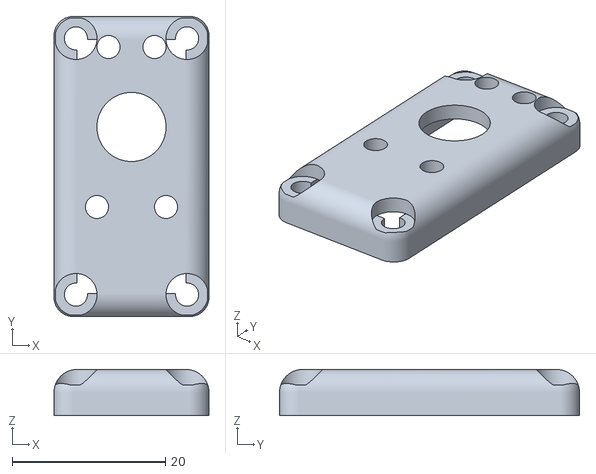
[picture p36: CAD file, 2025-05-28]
2.Mechanical/STL/Gripper-Lid.STL
20.2 x 39.1 x 6.00

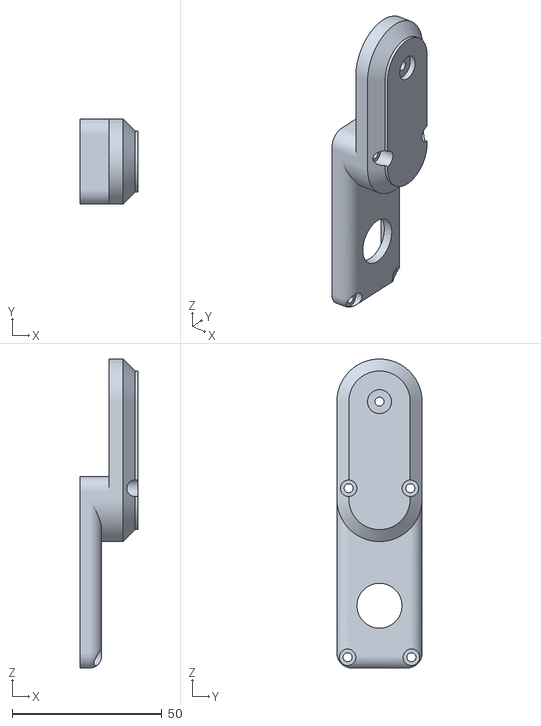
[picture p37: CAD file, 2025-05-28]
2.Mechanical/STL/Shoulder-Lid.STL
19.5 x 28.5 x 103.3

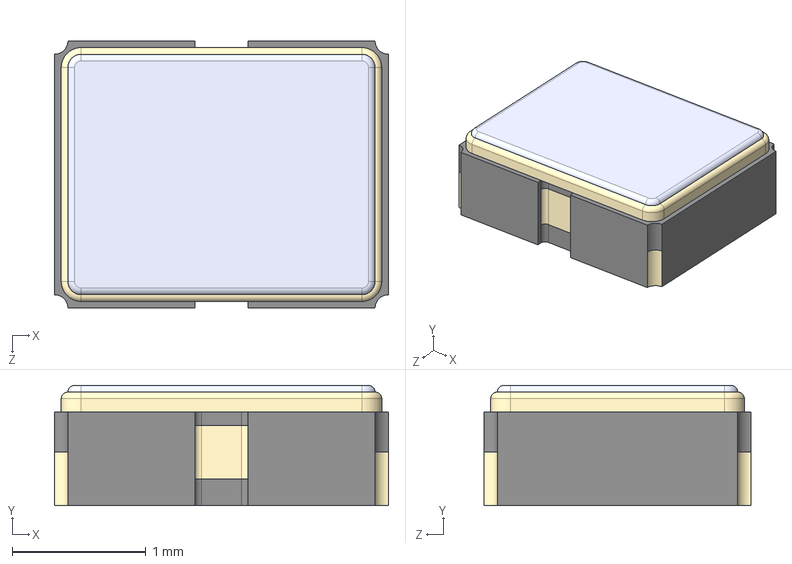
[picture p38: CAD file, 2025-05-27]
1.Electrical/RobotArmMK1.2/stepfiles/ECS-2520MV-160-CN-TR.step
2.50 x 0.9 x 2.00 mm

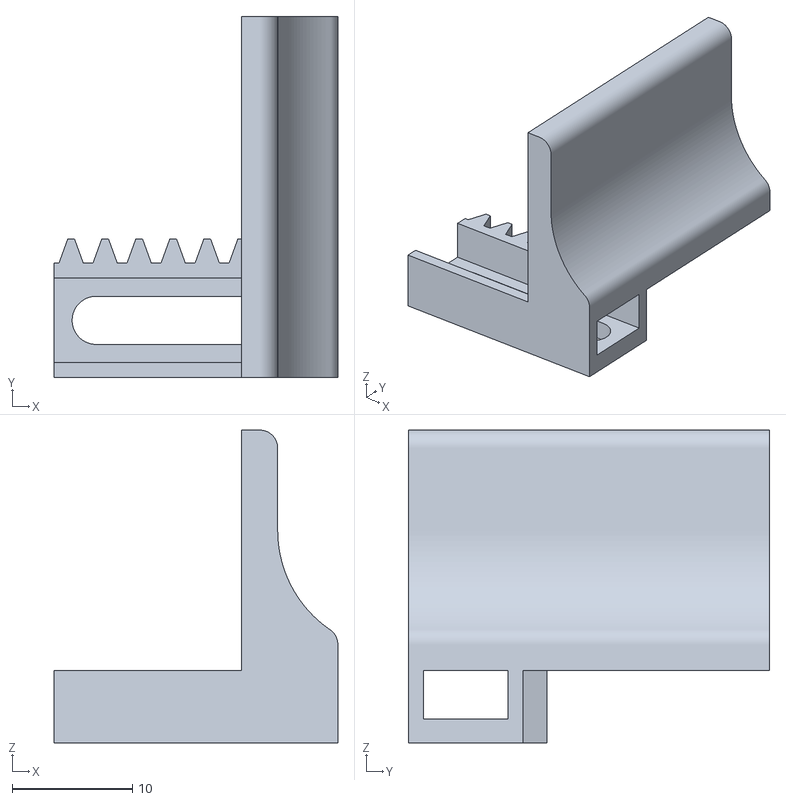
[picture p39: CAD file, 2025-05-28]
2.Mechanical/STL/Gripper-Rack.STL
23.6 x 30.0 x 26.0

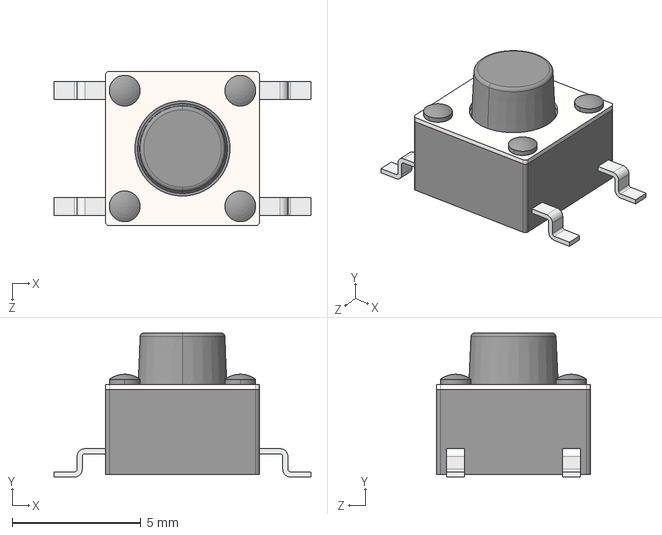
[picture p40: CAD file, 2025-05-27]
1.Electrical/RobotArmMK1.2/stepfiles/SMDPushButton-CUI_DEVICES_TS04-66-55-BK-260-SMT.step
10.0 x 5.60 x 6.00 mm

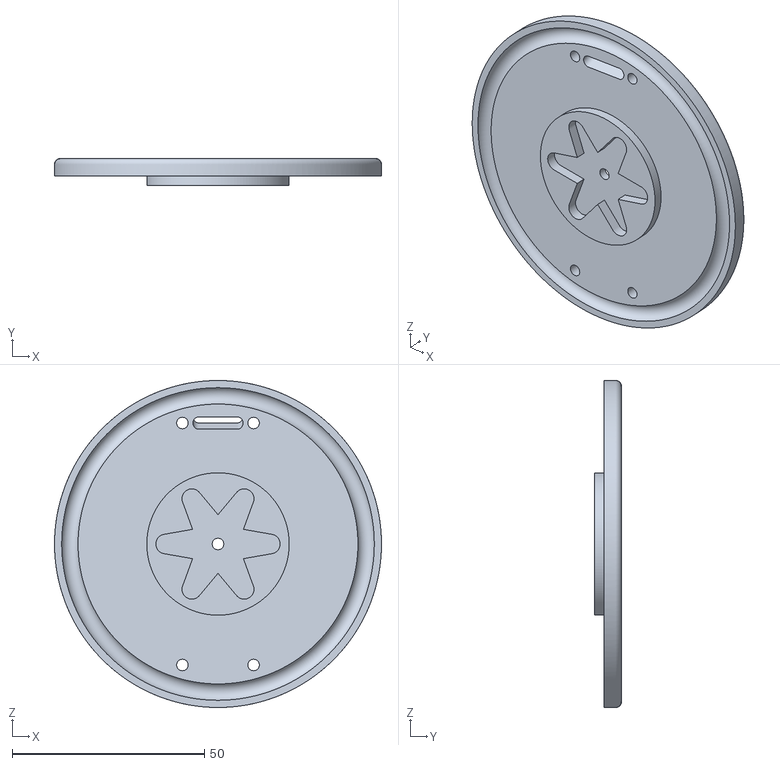
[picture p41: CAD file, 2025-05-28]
2.Mechanical/STL/Yaw-Body.STL
85.0 x 7.00 x 85.0

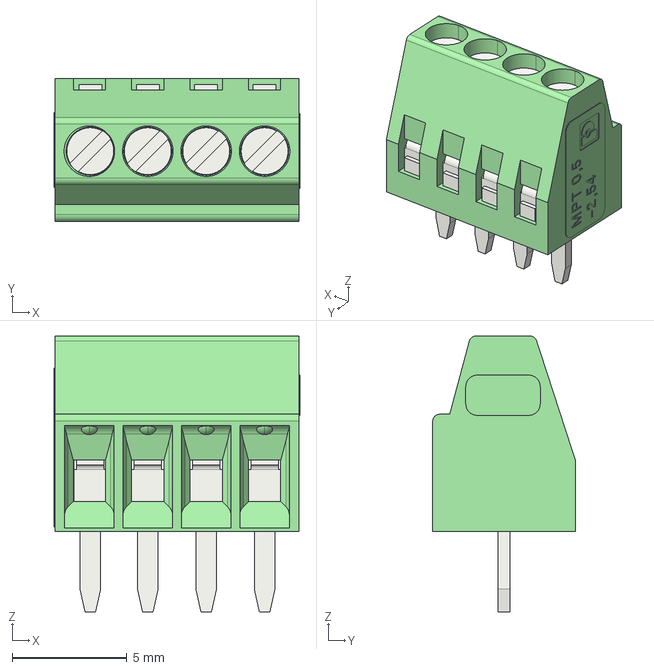
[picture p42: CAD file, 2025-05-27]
1.Electrical/RobotArmMK1.2/stepfiles/THT4TerminalBlock-1725672.step
10.7 x 6.20 x 12.0 mm

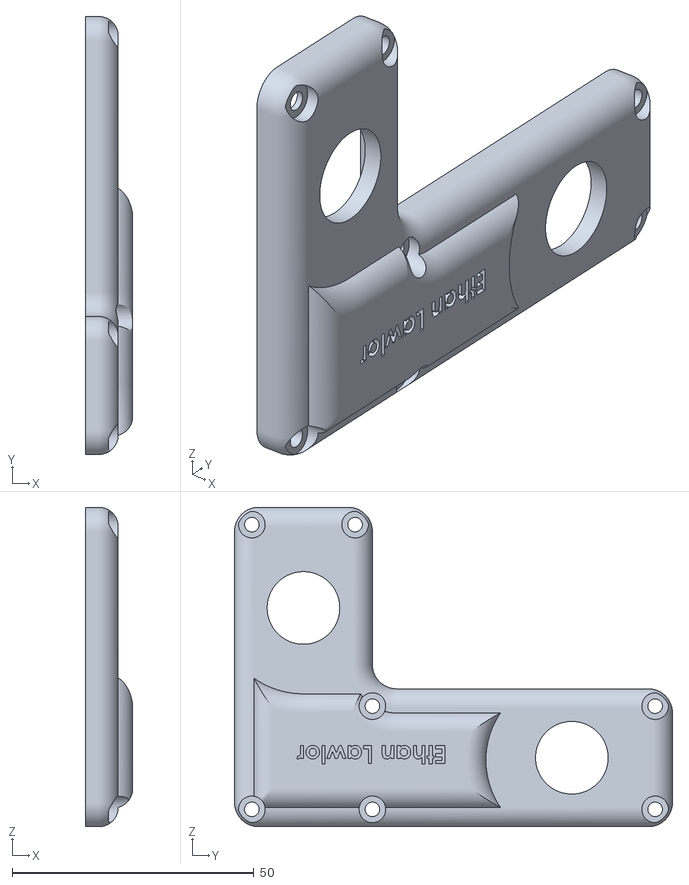
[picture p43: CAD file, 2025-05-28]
2.Mechanical/STL/UpperArm-Lid.STL
9.80 x 90.5 x 66.0

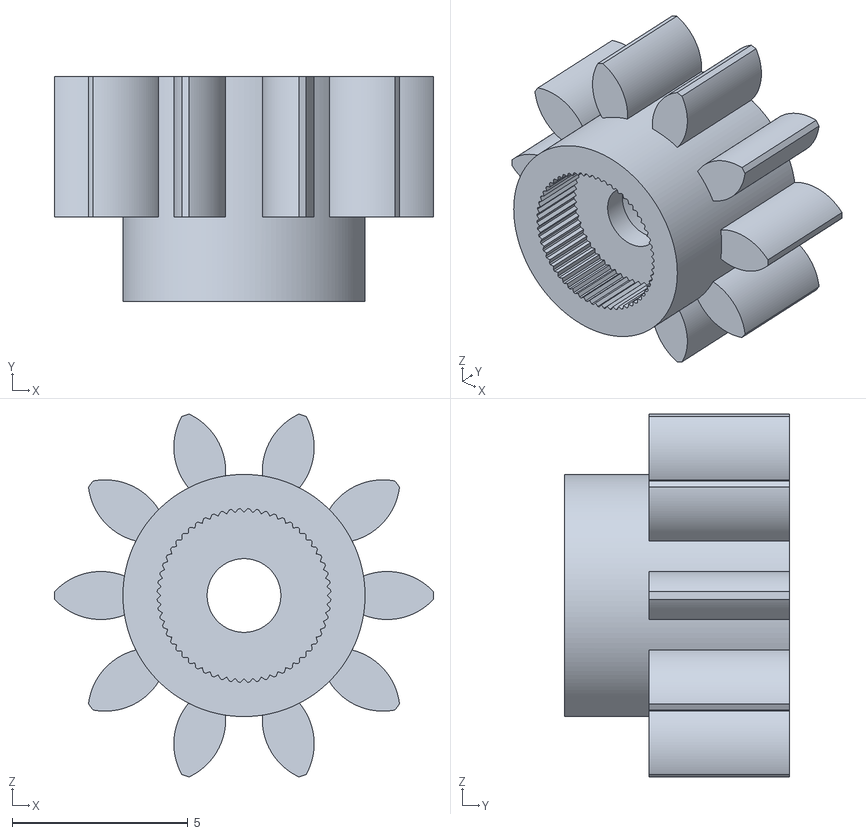
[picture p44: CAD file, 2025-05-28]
2.Mechanical/STL/Gripper-Gear.STL
10.8 x 6.40 x 10.3

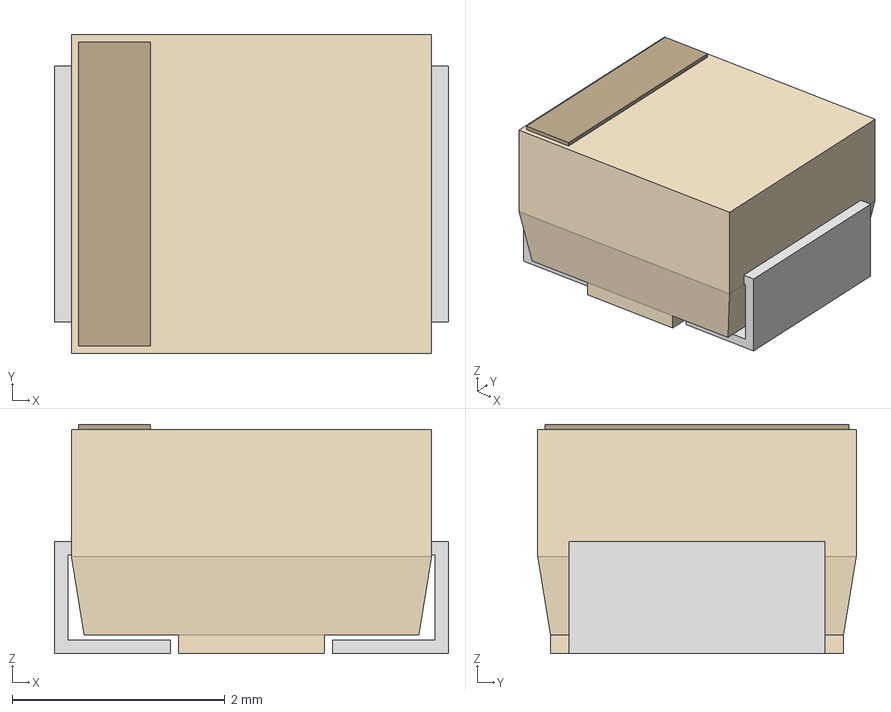
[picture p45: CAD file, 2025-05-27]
1.Electrical/RobotArmMK1.2/stepfiles/TAJB_AVX.step
3.71 x 3.00 x 2.16 mm

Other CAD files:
2.Mechanical/STL/Shoulder-Body.STL
2.Mechanical/STL/Controller-Body.STL
1.Electrical/RobotArmMK1.2/stepfiles/THT2TerminalBlock-1725656.step
1.Electrical/RobotArmMK1.2/stepfiles/1725656.stp
1.Electrical/RobotArmMK1.2/stepfiles/1725672.stp
2.Mechanical/STL/Base-Lid.STL
2.Mechanical/STL/Controller-Lid.STL
2.Mechanical/STL/Gripper-Body.STL
2.Mechanical/STL/UpperArm-Body.STL
2.Mechanical/STL/Wrist-Arm.STL
2.Mechanical/STL/Wrist-Body.STL
2.Mechanical/STL/Yaw-Left.STL
2.Mechanical/STL/Yaw-Right.STL

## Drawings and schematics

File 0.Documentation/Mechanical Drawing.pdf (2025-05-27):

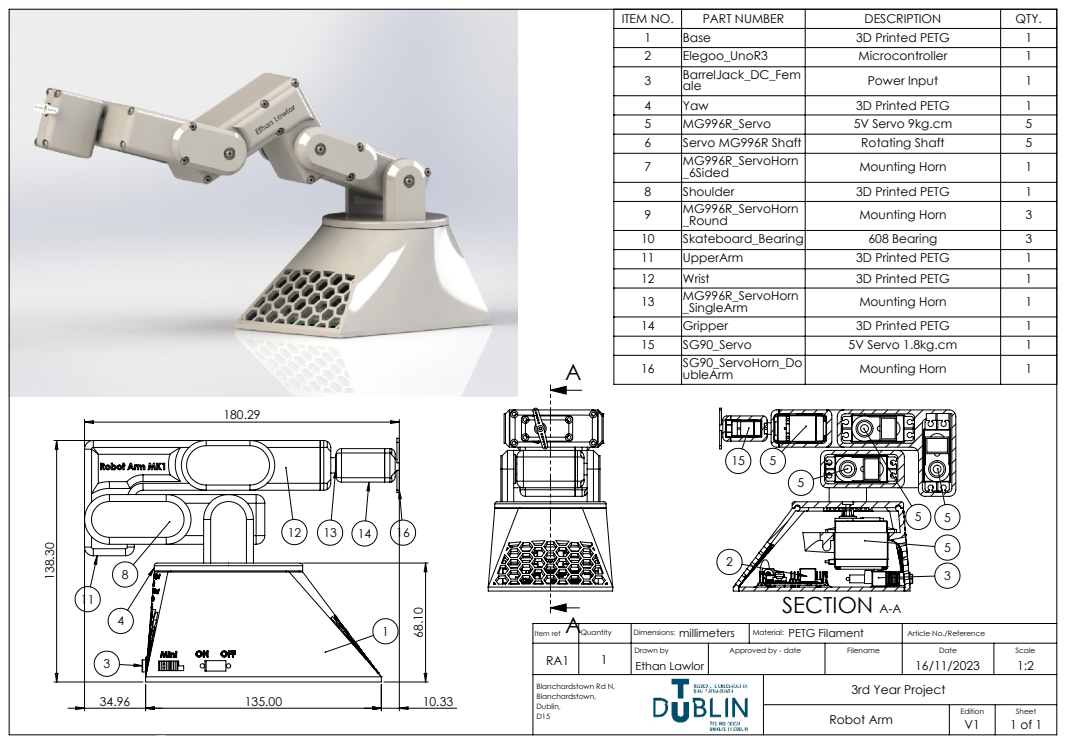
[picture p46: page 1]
SECTION A-A

ITEM NO. | PART NUMBER | DESCRIPTION | QTY.
1 | Base | 3D Printed PETG | 1
2 | Elegoo_UnoR3 | Microcontroller | 1
3 | BarrelJack_DC_Fem ale | Power Input | 1
4 | Yaw | 3D Printed PETG | 1
5 | MG996R_Servo | 5V Servo 9kg.cm | 5
6 | Servo MG996R Shaft | Rotating Shaft | 5
7 | MG996R_ServoHorn _6Sided | Mounting Horn | 1
8 | Shoulder | 3D Printed PETG | 1
9 | MG996R_ServoHorn _Round | Mounting Horn | 3
10 | Skateboard_Bearing | 608 Bearing | 3
11 | UpperArm | 3D Printed PETG | 1
12 | Wrist | 3D Printed PETG | 1
13 | MG996R_ServoHorn _SingleArm | Mounting Horn | 1
14 | Gripper | 3D Printed PETG | 1
15 | SG90_Servo | 5V Servo 1.8kg.cm | 1
16 | SG90_ServoHorn_Do ubleArm | Mounting Horn | 1

Item ref | Quantity | Dimensions: millimeters | PETG Filament Material: | Article No./Reference

RA1 | 1 | Drawn by Ethan Lawlor | Approved by - date | Filename | Date 16/11/2023 | Scale 1:2

Blanchardstown Rd N, Blanchardstown, Dublin, D15 | 3rd Year Project

Robot Arm | Edition V1 | Sheet 1 of 1

SOLIDWORKS Educational Product. For Instructional Use Only.

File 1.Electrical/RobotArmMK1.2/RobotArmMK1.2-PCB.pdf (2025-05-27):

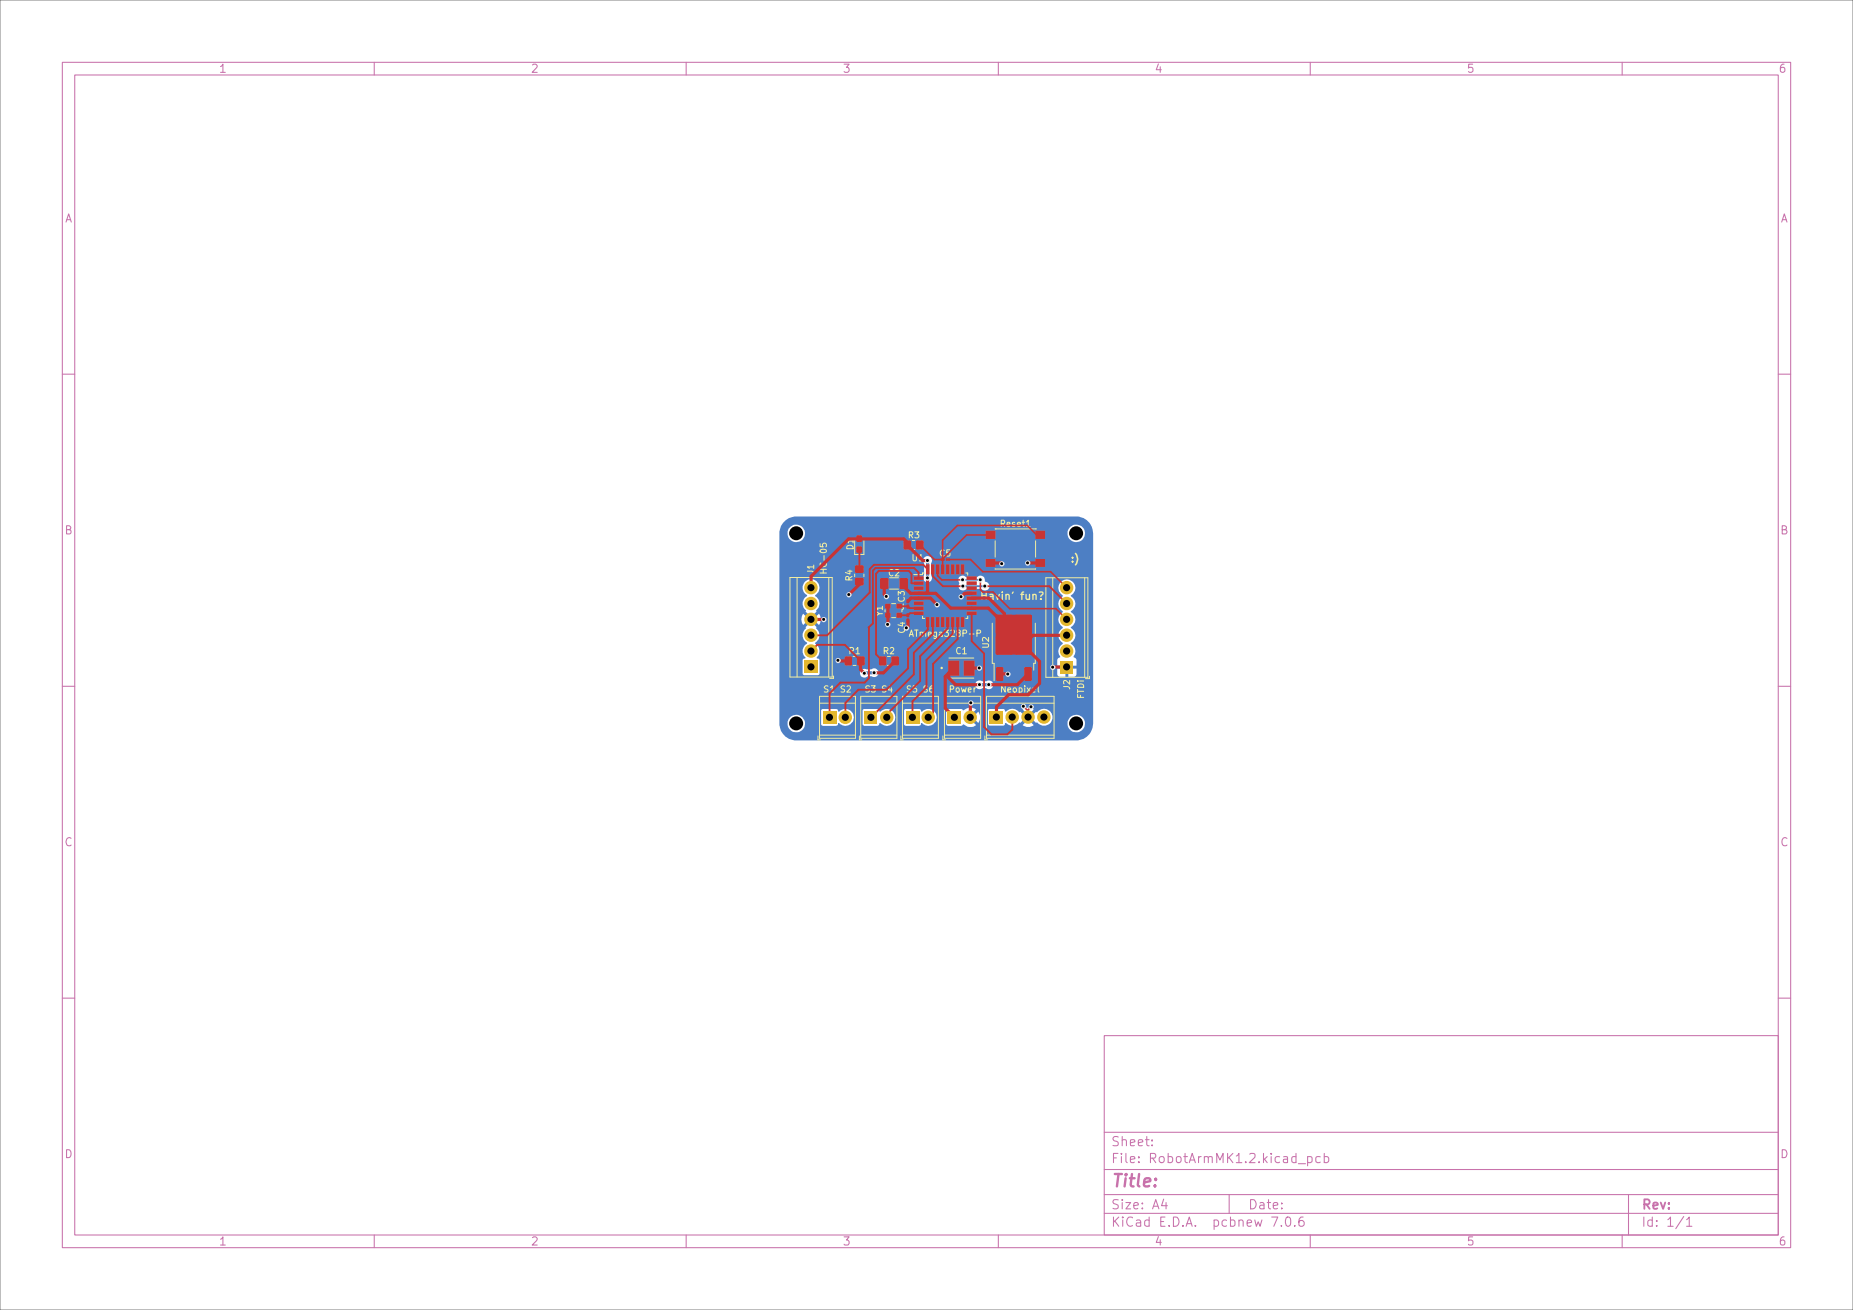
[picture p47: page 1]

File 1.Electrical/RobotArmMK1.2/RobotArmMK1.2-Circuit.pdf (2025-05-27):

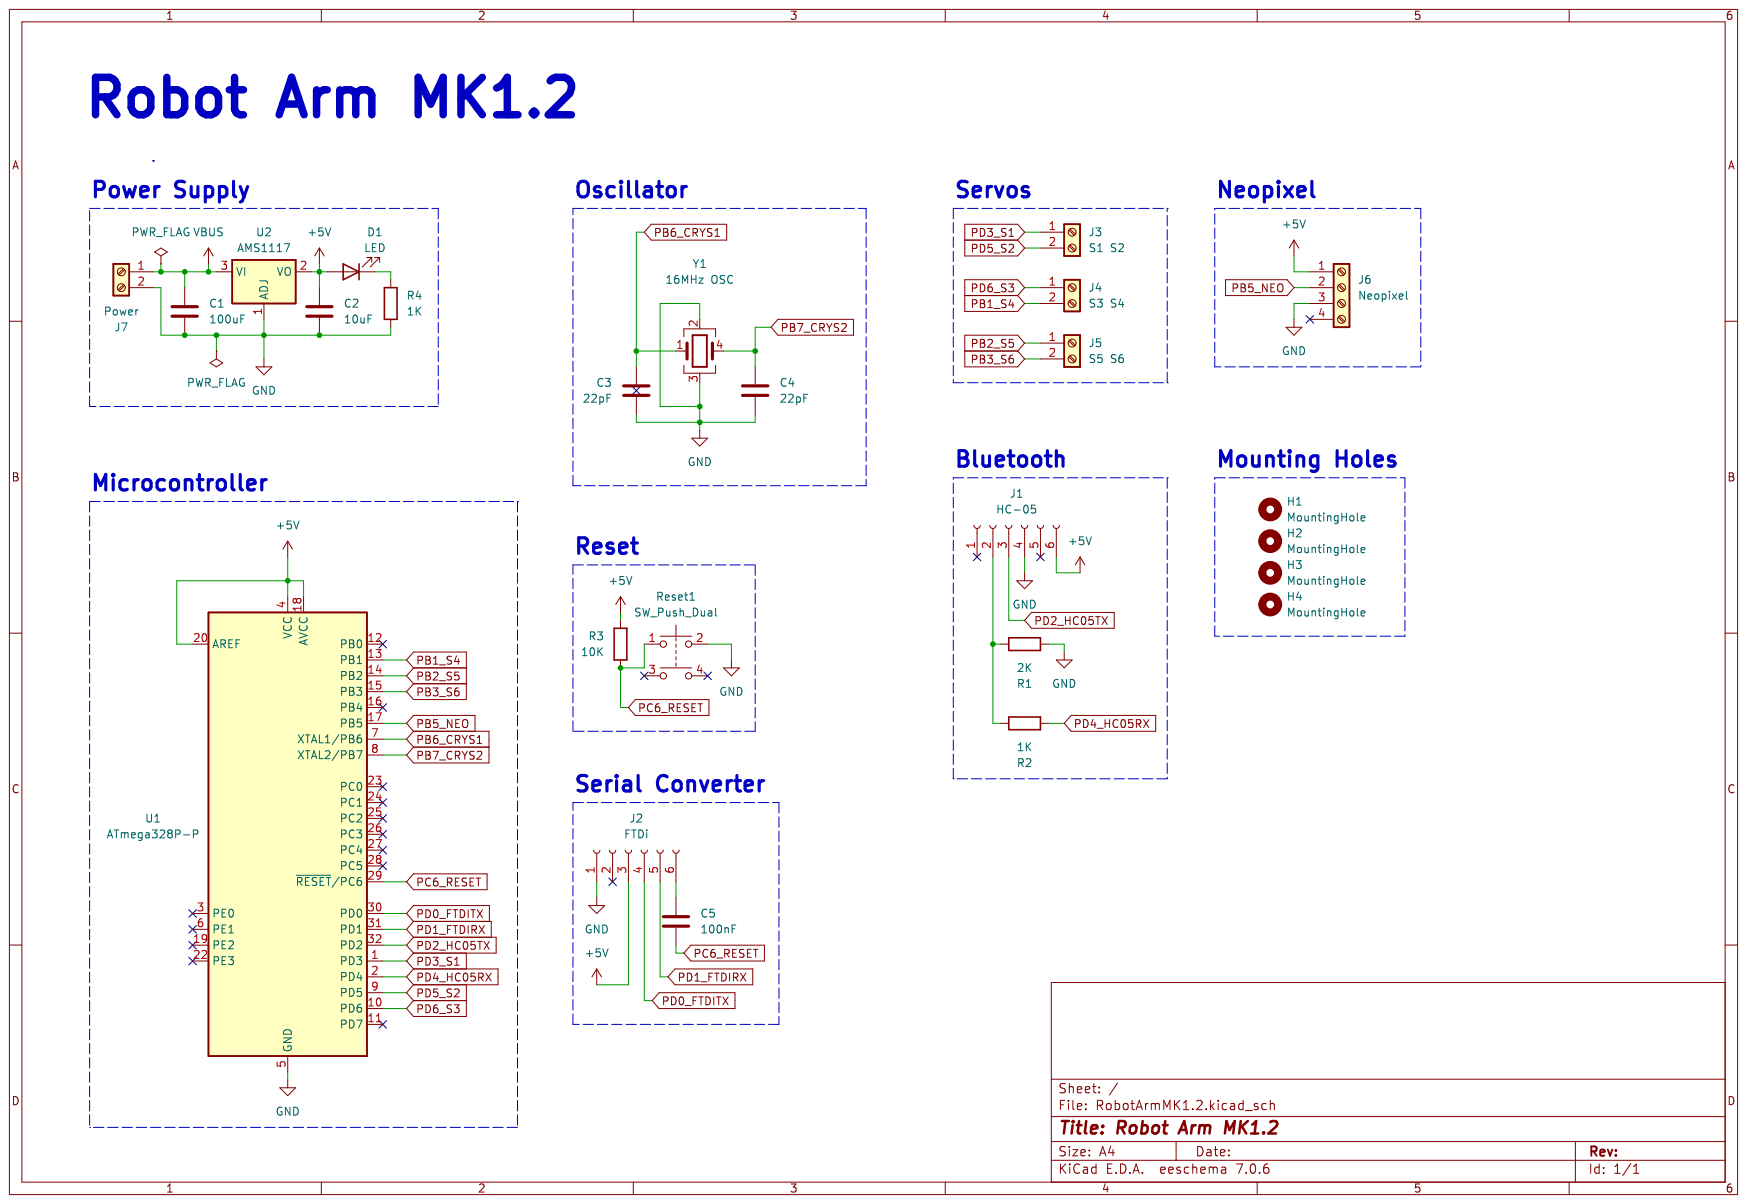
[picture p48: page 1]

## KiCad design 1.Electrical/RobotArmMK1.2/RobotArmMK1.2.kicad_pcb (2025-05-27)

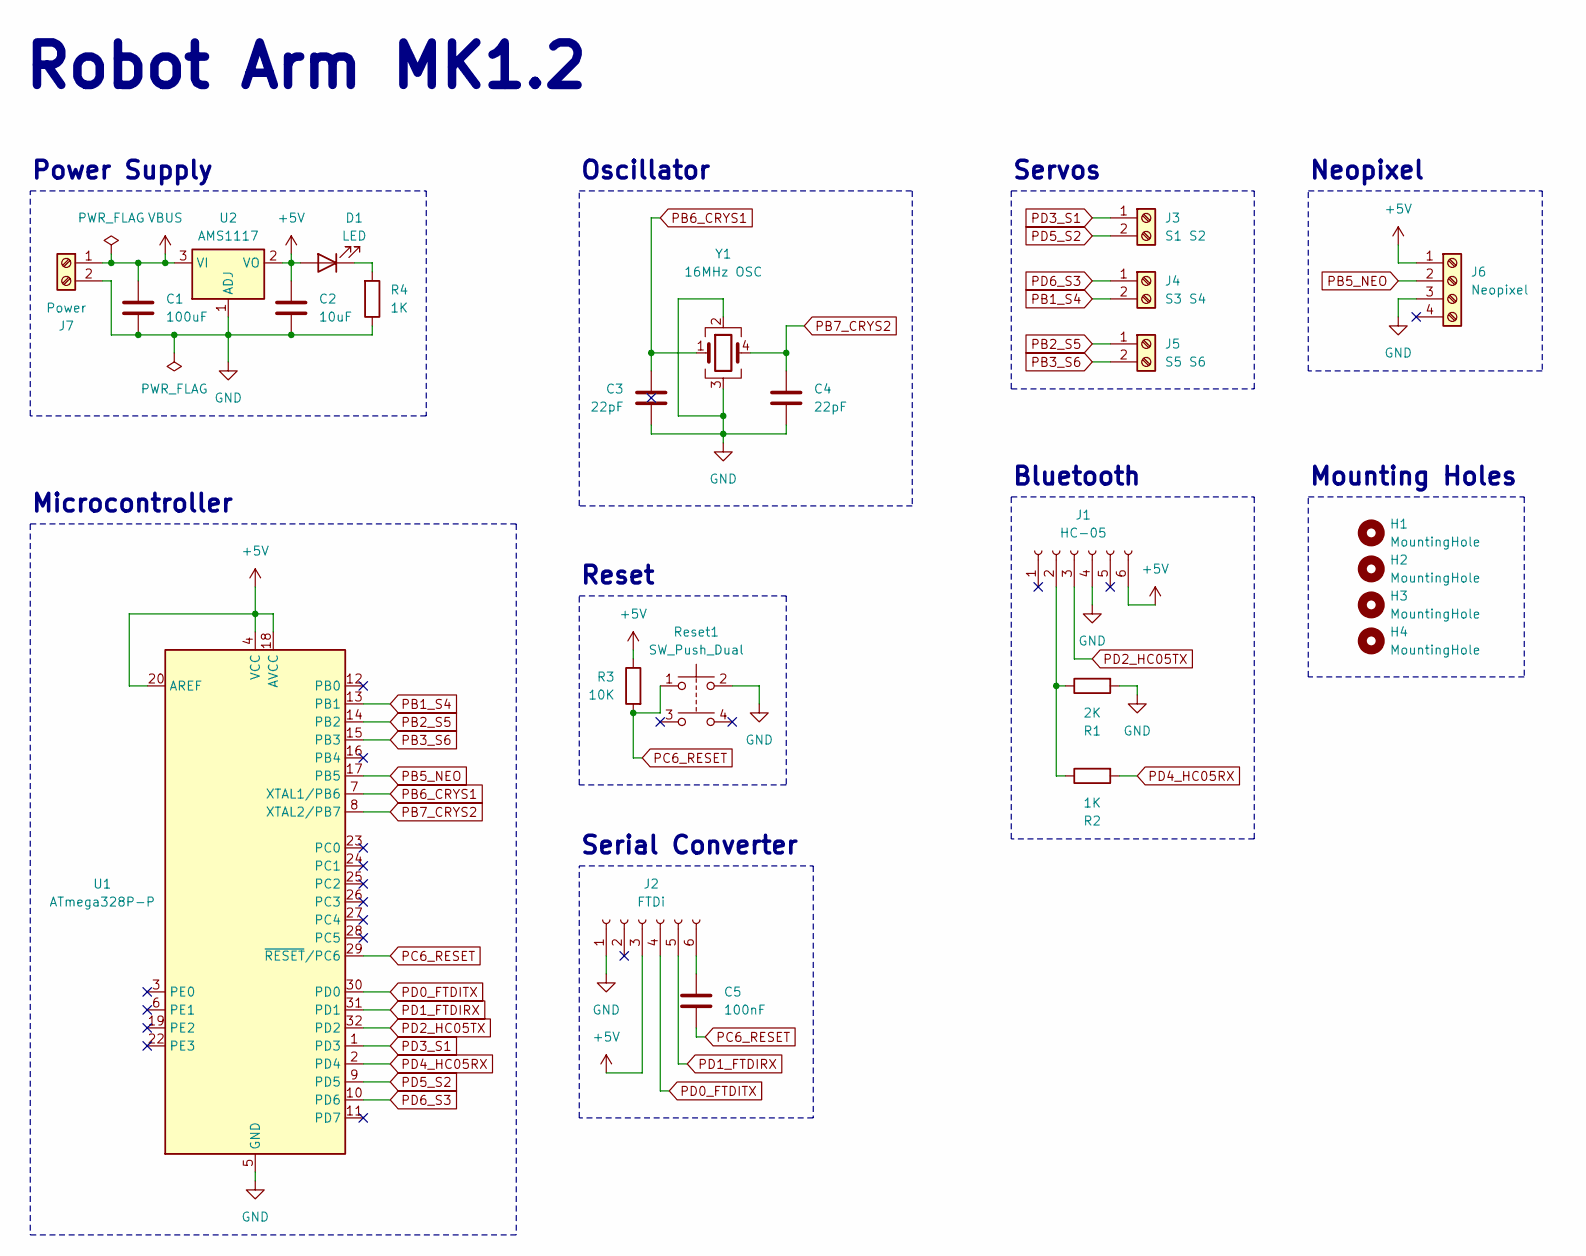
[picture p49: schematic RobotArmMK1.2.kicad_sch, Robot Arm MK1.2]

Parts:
C1: 100uF; TAJB_AVX-M
C2: 10uF; C_1206_3216Metric_Pad1.33x1.80mm_HandSolder
C3, C4: 22pF; C_0201_0603Metric_Pad0.64x0.40mm_HandSolder
C5: 100nF; C_0201_0603Metric_Pad0.64x0.40mm_HandSolder
D1: LED; LED_0603_1608Metric_Pad1.05x0.95mm_HandSolder
H1, H2, H3, H4: MountingHole; MountingHole_2.2mm_M2
J1: HC-05; TerminalBlock_TE_282834-6_1x06_P2.54mm_Horizontal
J2: FTDi; TerminalBlock_TE_282834-6_1x06_P2.54mm_Horizontal
J3: S1 S2; TerminalBlock_TE_282834-2_1x02_P2.54mm_Horizontal
J4: S3 S4; TerminalBlock_TE_282834-2_1x02_P2.54mm_Horizontal
J5: S5 S6; TerminalBlock_TE_282834-2_1x02_P2.54mm_Horizontal
J6: Neopixel; TerminalBlock_TE_282834-4_1x04_P2.54mm_Horizontal
J7: Power; TerminalBlock_TE_282834-2_1x02_P2.54mm_Horizontal
R1: 2K; R_0805_2012Metric_Pad1.20x1.40mm_HandSolder
R2, R4: 1K; R_0805_2012Metric_Pad1.20x1.40mm_HandSolder
R3: 10K; R_0805_2012Metric_Pad1.20x1.40mm_HandSolder
Reset1: SW_Push_Dual; SW_Push_1P1T_NO_6x6mm_H9.5mm
U1: ATmega328P-P; TQFP-32_7x7mm_P0.8mm
U2: AMS1117; TO-252-2
Y1: 16MHz OSC; Oscillator_SMD_ECS_2520MV-xxx-xx-4Pin_2.5x2.0mm

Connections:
+5V: C2.1, D1.2 (A), J1.6, J2.3, J6.1, R3.1, U1.4 (VCC), U1.18 (AVCC), U1.20 (AREF), U2.2 (VO)
GND: C1.2, C2.2, C3.2, C4.2, J1.4, J2.1, J6.3, J7.2, R1.2, R4.1, Reset1.2, U1.5 (GND), U1.21 (GND), U2.1 (ADJ), Y1.2, Y1.3
unnamed: D1.1 (K), R4.2
unnamed: J1.2, R1.1, R2.1
unnamed: C5.1, J2.6
PB1_S4: J4.2, U1.13 (PB1)
PB2_S5: J5.1, U1.14 (PB2)
PB3_S6: J5.2, U1.15 (PB3)
PB5_NEO: J6.2, U1.17 (PB5)
PB6_CRYS1: C3.1, U1.7 (XTAL1/PB6), Y1.1
PB7_CRYS2: C4.1, U1.8 (XTAL2/PB7), Y1.4
PC6_RESET: C5.2, R3.2, Reset1.1, U1.29 (~RESET/PC6)
PD0_FTDITX: J2.4, U1.30 (PD0)
PD1_FTDIRX: J2.5, U1.31 (PD1)
PD2_HC05TX: J1.3, U1.32 (PD2)
PD3_S1: J3.1, U1.1 (PD3)
PD4_HC05RX: R2.2, U1.2 (PD4)
PD5_S2: J3.2, U1.9 (PD5)
PD6_S3: J4.1, U1.10 (PD6)
VBUS: C1.1, J7.1, U2.3 (VI)

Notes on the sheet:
Power Supply
Serial Converter
Neopixel
Robot Arm MK1.2
Microcontroller
Servos
Oscillator
Reset
Mounting Holes
Bluetooth

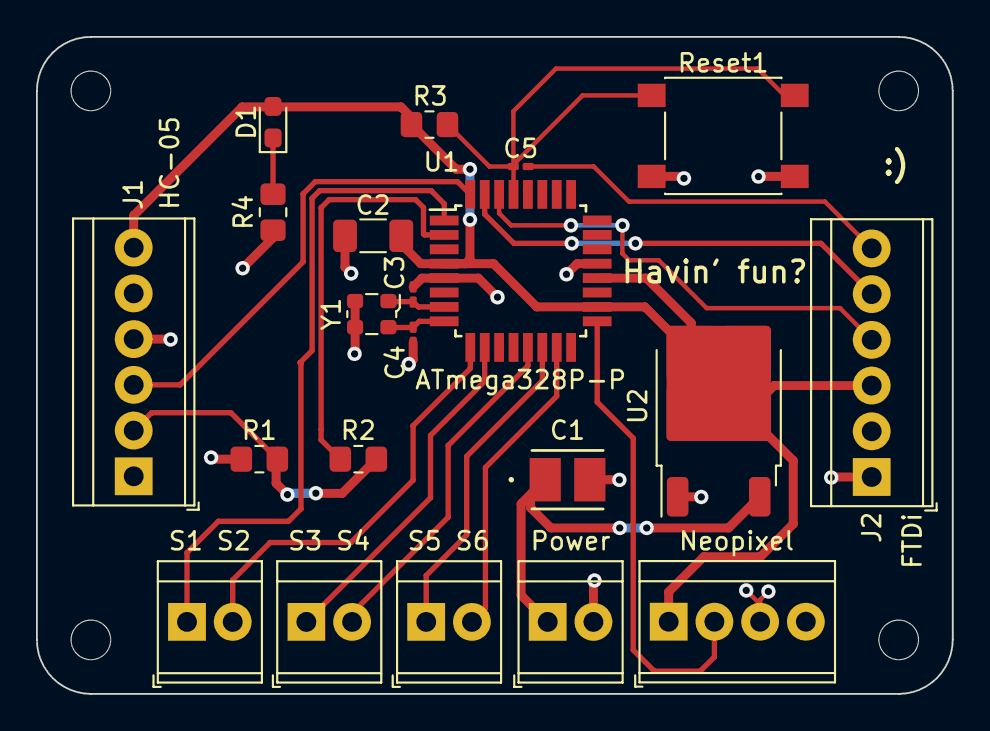
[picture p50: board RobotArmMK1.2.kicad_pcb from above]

Board: 2 copper layers, 50.9 x 36.5 mm, 25 parts (0 on the bottom side), 20 nets.
